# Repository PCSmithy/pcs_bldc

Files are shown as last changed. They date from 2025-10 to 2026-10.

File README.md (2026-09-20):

# pcs_bldc

A learning project for modeling and control of a brushless DC motor.

This is a personal reference project. The primary audience is the author, with
the intent to open-source it as a public example of what I believe quality
embedded software development, state estimation, and motor control should look
like end-to-end.

## Status

- **Hardware:** design finalized, layout complete. The board is frozen pending
  firmware work and will only be revised if firmware exposes a project-blocking
  issue.
- **Firmware:** foundation platform plus first motor drive — a spec'd and
  traced driver stack (clocks, GPIO, ADC, DMA, SPI, I2C, timers, USB CDC,
  op-amps, encoder, LED ring, button, serial) with all board sensing
  bench-verified in engineering units; six-step trapezoidal drive spinning
  the motor through the STSPIN32G4 gate driver, with USB-PD sink
  monitoring and overcurrent / encoder-fault protection; and a
  protobuf-over-USB protocol carrying telemetry, a signal trace engine
  sampling at the 20 kHz PWM rate, a link throughput test, and the log
  stream. FOC and estimation are ahead (see
  [`docs/motor-sprint.md`](docs/motor-sprint.md)).
- **Desktop app:** observability slice working on the bench — connect with
  a firmware-identity gate, DWARF-driven signal picker, live WebGL plots
  with honest min/max decimation, pause/zoom timeline with a comparison
  cursor, value table, and session restore. Spec-driven like the firmware
  ([`specs/desktop-app/`](specs/desktop-app/)), verified by a playwright
  UI suite.
- **Simulation and analysis tooling:** an SIL harness (`sw/sil`) exercises
  the native firmware build (protocol, trace engine, server); the
  high-fidelity motor-model SIL and the formal `notebooks/` analysis
  infrastructure are not yet started (ad-hoc trace analyses live in
  `tools/trace_analysis/`).

The hardware is a USB-PD-powered BLDC controller built around an STM32G431 MCU,
an STSPIN32G4 integrated gate driver, and an AS5048 magnetic rotor encoder. It
will live on the desk as an unloaded test stand; no production load profile is
in scope.

## Setup

Run `./setup.sh` from the repo root. It checks for required system tools
(Java 17+, Python 3.10+; KiCad 10 if you are doing hardware work), prints
install instructions for anything missing, and then installs project-local
artifacts (the OpenFastTrace JAR and the Python virtual environment). It is
idempotent and safe to re-run.

KiCad is required **only** for hardware design work. Contributors working on
firmware, SIL, analysis notebooks, or desktop tooling can ignore a
missing-KiCad warning and proceed.

Supported platforms are Windows and macOS. See
[`docs/setup.md`](docs/setup.md) for the full prerequisite table, what the
script does, verification steps, and troubleshooting.

## Project Goals

The project has four primary goals. Each is treated as a first-class
deliverable with its own specs, tests, and documentation. The goals are not
ordered by priority; they are interdependent and developed together.

### 1. Reference-quality embedded software development

Demonstrate, as a working example, what disciplined embedded software
development looks like end-to-end.

- **Architecture.** FreeRTOS-based, with clean abstraction layers, channelized
  module design for reuse, and no reliance on auto-generated framework code as
  the source of truth for application logic.
- **Spec-driven development with full traceability.** Every line of application
  code links to a software requirement; every requirement links forward to at
  least one test that covers it; every requirement derives from a higher-level
  parent (ultimately a project-goal section in this document). See
  [`docs/spec-system.md`](docs/spec-system.md).
- **Test infrastructure.** Unit tests for module-level logic; high-fidelity
  software-in-the-loop (SIL) tests as the primary verification surface. No
  hardware-in-the-loop (HIL) layer — once the motor is characterized, the SIL
  model is the test bench. Coverage targets are *spec coverage*, not just line
  coverage.
- **CI and quality gates.** Reproducible builds (pinned toolchain in a
  containerized dev environment), static analysis (clang-tidy / cppcheck),
  unit + SIL tests, and spec-traceability checks all enforced on every push.
- **Documentation as deliverable.** Code, specs, and analysis notebooks are
  written for an external reader from day one. The repository is intended to
  be public-ready throughout its life.

### 2. Modeling, simulation, and observability infrastructure

The infrastructure that supports learning and verification is itself a primary
deliverable, not an afterthought.

- **High-fidelity SIL model.** Motor electrical and mechanical model, gate
  driver and bridge model, sensor models (encoder, current shunts, bus
  voltage). Fidelity is set by what the estimators and controllers need to be
  developed and validated against — not by an abstract realism target.
- **System identification feeds the model.** Initial parameters are taken from
  measurements and datasheets to get the motor spinning. Auto-commissioning
  routines and online (augmented-state) parameter identification are scoped as
  later phases.
- **Real-time observability.** Rich USB-streamed telemetry (control loop
  internals, references, estimator states, raw sensor data) at meaningful
  rates, paired with a custom desktop visualizer / control app for live
  inspection, command, and tuning.
- **Offline analysis.** A Jupyter-notebook pipeline for post-hoc analysis with
  derivations, math overlays, and side-by-side comparisons. The notebooks
  carry the academic content of the project and are the primary artifact for
  re-learning estimation and control concepts at depth.
- **Algorithm comparison harness.** Code, SIL scenarios, and analysis pipeline
  structured so that swapping in a new estimator or controller, running the
  standard benchmark trajectories, and producing comparison plots is a small
  and repeatable workflow. The harness is designed to scale across many
  implementations even though the project may only execute on two or three of
  each.

### 3. State estimation

Re-learn and demonstrate optimal-estimation techniques on a real, instrumented
system. Pedagogical clarity and a strong intuition for filter behavior matter
as much as the filter "working."

- **Kalman-family observer** estimating motor position, velocity, acceleration,
  torque, and thermal state from phase currents, phase voltages, and rotor
  encoder position.
- **Validation in SIL before bench.** The SIL/observer pair is used to
  characterize convergence, noise sensitivity, and steady-state error before
  the filter ever sees the real motor.
- **Sensor-degradation experiments.** Systematically drop, delay, or corrupt
  sensor inputs in SIL to characterize filter robustness and to assess the
  feasibility of sensorless operation.
- **Sensorless extension.** Demonstrate sensorless estimation of position and
  velocity using an appropriate observer family (back-EMF, sliding-mode, HFI,
  or similar — selected during design).
- **Future phases.** Auto-commissioning of motor parameters; online
  augmented-state parameter identification.

### 4. Field-oriented motor control

Drive the motor cleanly under a hierarchy of control modes, using estimator
output as the feedback source so that estimation quality directly translates
into control quality.

- **Inner FOC torque loop**, both sensored and sensorless.
- **Outer loops:** constant velocity, constant torque, position control, and
  position trajectory tracking.
- **Repeatable trajectory benchmark.** A canonical position trajectory that
  can be replayed across estimator and controller variants under identical
  conditions, producing standard performance metrics (tracking error, control
  effort, settling time, current ripple, etc.) for side-by-side comparison.
  This benchmark is the primary scenario through which estimator and
  controller variants are evaluated.

## Non-goals

Explicitly out of scope, to keep the project tractable:

- Hardware-in-the-loop infrastructure. SIL is the simulation surface; the
  bench is everything else.
- Production-grade safety certification (DO-178, ISO 26262, or similar).
  Basic protections — overcurrent, overtemp, encoder-loss, gate-driver fault
  handling — are sufficient.
- Loaded operation, multi-motor systems, or specific application profiles
  (servo arm, drone, etc.). The motor is an unloaded desk test stand.
- Hardware revisions, unless firmware work exposes a project-blocking issue
  that cannot be worked around in software.
- Beating commercial motor-control SDKs on raw performance. Comparison against
  a baseline (e.g. ST Motor Control SDK) is interesting if it serves the
  learning goal, but is not a target in itself.

## Repository layout

| Path | Contents |
|---|---|
| `hw/` | KiCad 10 schematic and PCB design |
| `datasheets/`  | Reference PDFs for major ICs |
| `docs/` | Project-level documentation (spec system, setup, backlog) |
| `specs/` | OFT spec tree: `sys~` / `fw~` / `app~` requirements |
| `sw/` | All software: `fw/` firmware, `gui/` desktop app, `sil/` SIL harness, `lib/` shared C + Rust libraries, `proto/` board schema, `cmake/` toolchains |
| `tools/` | Project tooling: OFT wrapper, spec scripts, build scripts |
| `notebooks/` | Jupyter analysis notebooks (planned) |

`CLAUDE.md` contains working notes used by the AI assistant on this project.

## License

- Firmware, tooling, scripts, specs, and docs: **Apache-2.0** ([`LICENSE`](LICENSE)).
- Hardware design in [`hw/`](hw/): **CERN-OHL-W-2.0** ([`hw/LICENSE`](hw/LICENSE)).
- Vendored third-party code keeps its own license.

See [`LICENSES.md`](LICENSES.md) for the full map, including third-party components.

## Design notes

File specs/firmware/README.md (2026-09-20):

# Firmware specs

`fw~` requirements: STM32G4 firmware behavior, written in C/C++ on
FreeRTOS. Each spec needs at least one `impl` tag (in C/C++ source) and at
least one `test` tag (unit and/or SIL).

## Topics

Sub-folders are created when a topic gets its first spec.

- `architecture/` — task structure, ISR design, memory layout, build
  configuration
- `hal/` — hardware abstraction layer (hw-layer peripheral drivers: SPI,
  ADC, GPIO, DMA, timers, USB, op-amps, I2C). Uses per-peripheral sub-topic
  IDs, e.g. `fw~hal_spi_001~1`, `fw~hal_i2c_001~1`, `fw~hal_adc_001~1`,
  `fw~hal_usb_001~1`, `fw~hal_opamp_001~1`
- `io/` — generic, domain-independent io-layer infrastructure drivers (device
  abstractions layered over HAL buses). Per-bus sub-topic IDs, e.g.
  `fw~io_i2c_001~1` (IO_i2c generic per-device I2C driver over HW_I2C),
  `fw~io_bridge_001~1` (IO_bridge 3-phase motor-bridge driver over HW_TIM)
- `pd/` — USB-PD sink status: register decode and runtime for the CYPD3177
  controller, e.g. `fw~pd_001~1` (lib_CYPD3177 decode library)
- `mc/` — motor control, e.g. `fw~mc_001~1` (dev_gateDriver STSPIN32G4
  gate-driver management), `fw~mc_006~1` (app_motorControl gating and
  the PWM-synchronous commutation step), `fw~mc_013~1` (frame transforms
  and space-vector modulation), the six-step and V/f methods; also FOC,
  motion, trajectory tracking
- `est/` — estimation. Per-area sub-topic IDs, e.g. `fw~est_encoder_001~1`
  (AS5048 magnetic encoder driver), `fw~est_velocity_001~1` (encoder-derived
  velocity estimate); also the Kalman observer, sensorless observer, and
  parameter identification
- `obs/` — observability and on-device status indication. Per-area sub-topic
  IDs, e.g. `fw~obs_led_001~1` (SK6805 RGB LED string driver),
  `fw~obs_identity_*` (build identity), `fw~obs_status_001~1` (10 Hz status
  publication), `fw~obs_log_*` (printf log stream)
- `ui/` — on-device user-interface input drivers. Per-area sub-topic IDs, e.g.
  `fw~ui_switch_001~1` (dev_switch debounced button/switch driver)
- `conn/` — device↔app connectivity (the firmware side). Per-area sub-topic
  IDs: `fw~conn_serial_*` (IO_serial byte-stream transport over USB CDC),
  `fw~conn_proto_*` (protobuf schema + IO_COBSFrame framing),
  `fw~conn_server_*` (app_server request dispatch, link throughput
  test), `fw~conn_trace_*` (app_server trace services: PWM-cycle watch
  sampling and batched streaming, memory read/write, trace capability
  report)
- `safety/` — fault state machine, protection thresholds, recovery
  paths

## Tagging conventions in firmware code

```c
// [impl->fw~foc_park_transform~1]
void foc_park_transform(...) { ... }
```

```c
// [test->fw~foc_park_transform~1]
TEST(foc, park_transform_matches_reference) { ... }
```

A single piece of code can carry multiple tags if it implements multiple
specs (rare; usually a sign you should split the code).

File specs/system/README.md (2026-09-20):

# System specs

`sys~` requirements: what the system as a whole must do, including how the
STM32G4 firmware and the Rust desktop app cooperate.

Each `sys~` spec declares which downstream components it requires for
coverage on a per-spec basis:

- `Needs: fw, test` — firmware-only behavior (e.g. closed-loop current
  control runs at 20 kHz on the MCU).
- `Needs: app, test` — desktop-app-only behavior (e.g. the user can change
  the live-plot color scheme).
- `Needs: fw, app, test` — cross-component behavior (e.g. the user can
  configure motor parameters via the GUI and have them persisted in
  firmware NVRAM).

System-level tests are typically SIL scenarios or end-to-end integration
tests that exercise the full stack. SIL is the primary verification surface
for this project.

## Start here

- [[overview|System overview]] — block diagram, two-component architecture,
  external/internal interfaces, operating-mode state machine, persistence,
  plurality. Contains the small set of architectural anchor `sys~` specs
  (standalone device, app as auxiliary, USB CDC transport, mode FSM, NVRAM,
  multi-device).

## Topics

Sub-folders are created when a topic gets its first spec. The topics below
are the anticipated structure; folders that are not yet present have no
specs in them yet.

- `mc/` — sensored & sensorless motor control (anchor `sys~mc_001`), torque,
  velocity, position, trajectory tracking; gate-driver management (anchors
  `sys~mc_002` configuration, `sys~mc_003` fault observability); bridge
  actuation (`sys~mc_004`), the commutation-method architecture
  (`sys~mc_005`), and control-loop timing (`sys~mc_006`)
- `est/` — state estimation, sensorless operation
- `conn/` — device↔app protocol: schema-defined messages
  (`sys~conn_001`), message framing (`sys~conn_002`), request
  acknowledgement (`sys~conn_003`), link throughput test
  (`sys~conn_004`)
- `obs/` — observability: periodic status telemetry (`sys~obs_001`),
  signal selection from firmware debug information (`sys~obs_002`),
  firmware build identity + gate (`sys~obs_003`/`_004`), signal trace
  (`sys~obs_005`), signal write (`sys~obs_006`), text log stream
  (`sys~obs_007`), memory read (`sys~obs_008`), trace capability report
  (`sys~obs_009`)
- `ops/` — system mode state machine (idle / calibrate / run / fault),
  command authority (`sys~ops_002`, [[command-authority]]), mode
  transitions (anchor `sys~ops_001` lives in [[overview]])
- `safety/` — protections (overcurrent, overtemp, encoder-loss,
  gate-driver fault), fault recovery
- `pd/` — USB-PD sink power monitoring (anchor `sys~pd_001`), power-up
  sequencing, brown-out recovery

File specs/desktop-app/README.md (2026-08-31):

# Desktop app specs

`app~` requirements: the Rust + webview desktop app (`sw/gui/`) for
observing, commanding, and configuring the device. Each spec needs at
least one `impl` tag (in Rust source) and at least one `test` tag (unit
and/or integration).

## Topics

Sub-folders are created when a topic gets its first spec.

- `arch/` — process split and state ownership ([[core-ownership]]:
  device and firmware state live in the native core;
  [[session-restore]]: the saved port/ELF/watch-list context)
- `conn/` — device session and protocol client ([[session]]), framing
  + envelope codec ([[wire]])
- `obs/` — the acquisition model: ELF/DWARF signal selection
  ([[signal-picker]]), the build-identity gate ([[access-gate]]), the
  trace client and Samples demultiplexer ([[trace-client]])
- `views/` — presentation surfaces: [[live-plot]] (plot, axes, trace
  appearance, decimation), [[telemetry]], [[log]], [[workspace]],
  [[cursor]] (cursor, pointed trace, comparison anchor + deltas),
  [[table]], [[timeline]], [[watch-panel]], [[render-budget]]
  (rendering performance floor), and [[value-rendering]] (the
  surfaces' shared value formatting)

Convention: `obs/` holds acquisition and access — what bytes mean and
when capabilities are available; `views/` holds presentation surfaces —
what the user sees.

## Tagging conventions in Rust code

```rust
// [impl->app~conn_001~1]
fn open_session(port: &str) -> Result<Session> { ... }
```

```rust
// [test->app~conn_001~1]
#[test]
fn session_reopens_after_port_returns() { ... }
```

A single piece of code can carry multiple tags if it implements multiple
specs (rare; usually a sign you should split the module).

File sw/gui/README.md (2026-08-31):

# pcs_bldc — GUI operator app

A Rust + webview (Tauri 2) desktop app for connecting to the pcs_bldc
board: observability (DWARF signal selection, live trace plotting,
telemetry, logs), command, and diagnosis over the USB serial protocol.
Requirements live in `specs/desktop-app/` (`app~` specs).

Layout:

- `src-tauri/` — the native core (own Cargo workspace + lockfile). All
  device I/O, protocol state, and loaded-ELF state lives here
  (`app~arch_001~1`); shared logic comes from the `sw/lib/rust` crates
  (`pcs_wire`, `pcs_proto`, `dwarf_map`).
- `dist/` — the static webview frontend (no JS toolchain; plain
  HTML/JS served via `frontendDist`, `withGlobalTauri` for `invoke`).

Build/run from `src-tauri/`: `cargo build`, `cargo tauri dev` (or
`cargo run` for the plain window).

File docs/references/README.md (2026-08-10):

# References

Papers backing the project's control design. Large PDFs stay out of the
repo where possible — cite title + DOI here instead.

## Future controls references

- Prabhu, N., Rajaram, T., Ashok, B., "Design of sliding mode model
  predictive dual-loop control through self-learning strategy to mitigate
  the torque ripple in BLDC motor for electric vehicles."
  Scientific Reports 15, 45617 (2025).
  https://doi.org/10.1038/s41598-025-29445-w

## In-repo

- `actuators-14-00400-v2.pdf` — Abouseda, A.I., Doruk, R., Emin, A.,
  Akdeniz, O., "Modeling, Dynamic Characterization, and Performance
  Analysis of a 2.2 kW BLDC Motor Under Fixed Load Torque Levels and
  Variable Speed Inputs: An Experimental Study." Actuators 14, 400 (2025).
  https://doi.org/10.3390/act14080400

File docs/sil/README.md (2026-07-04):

# SIL (Software-in-the-Loop) testing environment

> **Picking this up fresh? Start with [`handover.md`](handover.md)** — current
> status, code map, how to run, and the prioritized next steps.

This directory holds the planning + architecture docs for the pcs_bldc SIL
environment: a Rust framework (**`voyant`**) that runs the **native
cross-compiled C firmware** against simulated plant models, with white-box
inspection of firmware state during execution.

Two run modes share one core engine:

- **Realtime mode** — sim time tracks wall-clock. Hosts a web dashboard
  (signal plotting, injection, live model tweaks) and presents a USB-CDC
  endpoint so the desktop app can't tell it apart from the real board.
- **Fast mode** — faster-than-realtime, fully scripted via Python/pytest
  bindings. Deterministic, parallelizable, for automated regression.

## Build & run

```bash
tools/run_sil.sh            # build native firmware (DLL) + SIL framework, run the sim
tools/run_sil.sh --clean    # wipe the native build dir first
```

Builds the firmware as a shared library (`build/native-fw/src/libpcs_bldc_fw.dll`),
builds the `sw/sil/` Rust workspace, and runs `sil-core`, which loads the
firmware, drives it over the control ABI, and reads its state by symbol.

## Documents

| Doc | Purpose |
|-----|---|
| [`architecture.md`](architecture.md) | The technical architecture: execution model, sim boundary, time/scheduler core, plant models, Rust↔C boundary, the two run modes, and the open decisions. **Read this first.** |
| [`state-route-tables.md`](state-route-tables.md) | The two core framework data structures: the **State Table** (every firmware static + model states; traced entries are change-logged historians) and the **Route Table** (declarative per-tick transport). |
| [`signal-trace.md`](signal-trace.md) | D12 — the State Table as historian: change-logged, timestamped per-signal timeseries that Python tests evaluate against. |
| [`ffi-boundary.md`](ffi-boundary.md) | D2 — Rust↔C boundary: in-process, dynamically-loaded firmware, DWARF memory introspection, tiny control ABI + C→Rust upcalls. |
| [`freertos-tick.md`](freertos-tick.md) | D1 — single-threaded cooperative FreeRTOS **fiber** port + pluggable tick source (realtime vs framework-driven). |
| [`performance.md`](performance.md) | The performance architecture: cost model + levers (fibers, gated discrete work, better integrators, dirty-page historian, zero-alloc) + the seams baked in from the start. |
| [`sim-interrupts.md`](sim-interrupts.md) | D8 — framework-owned interrupt table (periodic + one-shot, config + runtime); dispatched through the port in the firmware fiber context. |
| [`inverter-timestep.md`](inverter-timestep.md) | D6 — inverter fidelity (averaged-duty default, switching-resolved opt-in), the abc model↔firmware contract, and base `dt`. |
| [`time-virtualization.md`](time-virtualization.md) | D9 — firmware time sources backed by the sim clock; every wait is a yield (busy-waits would deadlock). |
| [`determinism.md`](determinism.md) | D7 — tolerance-based float assertions (ε≈1e-6) over a reproducible engine; the discrete threshold-divergence caveat. |
| [`roadmap.md`](roadmap.md) | Phased milestones + status tracking for building it out. |

## Worktree / branch workflow

This work lives on the **`sil`** branch, developed in a separate worktree so
`main` stays free for parallel work:

```
C:/code/pcs_bldc       main   (hardware + firmware)
C:/code/pcs_bldc-sil   sil    (this SIL effort)
```

- **Rebase cadence:** periodically `git fetch && git rebase main` from the
  `sil` worktree to pull in firmware/build changes. The SIL effort requires
  real firmware-side work — running FreeRTOS and the io/dev/app layers on
  the SIM target (today they're gated `BUILD_TARGET_STM32G4`-only), plus a
  sim ABI for the framework to drive. Keep these changes clean and
  upstream-friendly to reduce rebase friction; much of it (ungating layers,
  sim impls of low-level drivers) is genuinely useful on `main` regardless.
- **Merge back:** once the harness is proven, merge `sil` into `main`. The
  firmware-side changes (native FreeRTOS port wiring, ungating the upper
  layers for SIM, sim impls of the bottom-layer drivers, a sim ABI/entry
  point) are the parts that touch shared files; the Rust framework under
  `sw/sil/` is purely additive.

## Confirmed ground rules

1. Framework is **Rust**.
2. Runs the **native** firmware build (`BUILD_TARGET_SIM`), not an ARM
   emulator — for speed, determinism, and parallelism. An ARM-emulation
   backend stays a future option behind a clean execution-backend seam.
3. The sim plugs in at the existing **HAL/channel boundary**
   (`sw/lib/c/shared/hw/<Module>/sim/`). Only the genuinely
   hardware-specific bottom layer is swapped.
4. **FreeRTOS and the io/dev/app layers run on the SIM target too** — the
   real scheduler and the real task code execute in sim, not a re-host of
   the logic. (Today they're gated `BUILD_TARGET_STM32G4`-only; making them
   build + run on SIM is the bulk of the firmware-side work.)
5. White-box inspection is via the **native `.elf`/shared-lib symbol table
   (+ DWARF)** — read/write firmware globals by name during execution. **No
   sim-specific getter/setter functions in the firmware.**
6. The framework's two core data structures are the **State Table** (one
   namespace over every firmware static + all model states) and the **Route
   Table** (per-tick `source → destination` transport). See
   [`state-route-tables.md`](state-route-tables.md).
7. **Single-threaded cooperative fibers, performance-first.** The whole sim runs
   in one OS thread (tasks = fibers); the hot loop is engineered for many×
   realtime on a normal desktop. See [`performance.md`](performance.md).

See [`architecture.md`](architecture.md) for the reasoning and the decisions
still open.

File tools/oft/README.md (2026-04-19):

# OpenFastTrace (project-local install)

This directory holds a project-local install of
[OpenFastTrace](https://github.com/itsallcode/openfasttrace) (OFT), the
spec-traceability tool described in
[`docs/spec-system.md`](../../docs/spec-system.md).

## Requirements

- Java 17 or later on `PATH`. The wrappers will fall back to a
  `C:\Program Files\Microsoft\jdk-*-hotspot` install if `java` is not on
  `PATH` (useful right after a fresh winget install before the shell is
  restarted).

## Setup

The JAR itself is not committed. To download the project-pinned version
and verify its SHA256:

```bash
tools/oft/install.sh
```

Re-running `install.sh` is idempotent.

## Usage

From bash:

```bash
tools/oft/oft.sh trace specs/ src/ test/
tools/oft/oft.sh trace -o html -f trace.html specs/ src/ test/
tools/oft/oft.sh help
```

From cmd.exe:

```
tools\oft\oft.cmd trace specs\ src\ test\
```

## Pinned version

OFT is pinned to **4.2.2**. The version string lives in three files
(`install.sh`, `oft.sh`, `oft.cmd`). To upgrade, edit all three; the SHA256
is fetched from the upstream release alongside the JAR, so there is no
hand-maintained checksum.

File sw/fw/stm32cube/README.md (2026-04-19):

STM32Cube artifacts - driven by HW design, not active development

use converter script to convert cube outputs into /src/ format for project development

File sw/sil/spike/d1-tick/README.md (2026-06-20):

# D1 spike — cooperative fiber FreeRTOS port

Proves the load-bearing assumption of the whole SIL design (see
[`docs/sil/freertos-tick.md`](../../../../docs/sil/freertos-tick.md) §8 and
[`docs/sil/performance.md`](../../../../docs/sil/performance.md) Lever 1):
a **single-threaded cooperative fiber** FreeRTOS port is **deterministic** *and*
**many× faster than realtime**.

## What it is

A native (host) FreeRTOS V10.3.1 build with a hand-written **fiber port**:

- one OS thread; each task is a **Windows fiber**; the driver is the main fiber
- context switches are **fiber swaps** at cooperative points only
- the tick is **framework-driven** — the driver calls `vSilAdvanceTick()`
- quiescence (all tasks blocked → idle) hands control back to the driver via the
  idle hook (`vApplicationIdleHook` → `vPortYieldToScheduler`)

Two tasks exercise the scheduler: **A** (prio 3, 1 ms) and **B** (prio 2, 5 ms).

## Files

| File | Role |
|---|---|
| `port.c` / `portmacro.h` | the cooperative fiber port |
| `FreeRTOSConfig.h` | native config (cooperative, idle-hook handoff, timers off) |
| `spike.c` | driver + two tasks + idle hook; trace and bench modes |
| `build.sh` | build with MinGW gcc |

## Build & run

```bash
bash build.sh
./d1_spike.exe              # trace mode: per-tick task activity to stdout
./d1_spike.exe bench 50000000   # bench mode: ticks/s + x-realtime to stderr
```

## Results (MinGW gcc 15.2, one desktop)

**Determinism — PASS.** 30 serial + 16 parallel runs of trace mode are
**bit-identical**. Trace shows A every tick, B every 5th, A before B when both
are ready (priority order) — correct FreeRTOS scheduling, reproducibly.

**Performance — PASS.** ~**5.0 Mticks/s ≈ 5000× realtime** on one core at a
1 kHz tick — and this is a heavy case (A wakes *every* tick, so every tick does a
full switch in/out). 8 parallel sims hold ~4.3 Mticks/s each (~13% contention
loss) → near-linear scaling.

## What it proves / scope

- Validates the **fiber execution engine** (determinism + throughput) — the
  riskiest assumption — before anything is built on top.
- Raw scheduler-tick cost only; models, routes, historian, and real firmware
  come later and add per-tick cost. At a finer production base `dt` (a few µs),
  ~5 Mticks/s is ~10× realtime for the bare tick before that work.
- Windows fibers directly (Windows-first). The cross-platform context-switch
  primitive (macOS `ucontext` / small asm) is a later roadmap item.
- Throwaway scaffolding: the production port reuses this structure but lives in
  the canonical FreeRTOS portable layout.

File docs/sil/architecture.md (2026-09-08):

# SIL architecture

Status: **draft / planning.** This captures the agreed ground rules and the
decisions still open. It is a living doc — update it as decisions land.

## 1. Goal

A Rust framework that runs the **native cross-compiled pcs_bldc firmware**
against simulated plant models (motor, encoder, sensors, power), with
white-box access to firmware state, in two modes:

- **Realtime** — sim time == wall-clock; web dashboard; presents a USB-CDC
  endpoint the desktop app talks to as if it were the real board.
- **Fast** — faster-than-realtime, deterministic, scripted from Python
  (pytest), parallelizable for regression.

## 2. The big picture

```
            ┌─────────────────────────── Rust SIL framework ──────────────────────────┐
            │                                                                          │
  pytest ──┐  ┌───────────┐   ┌────────────────────────┐   ┌────────────────────────┐
  (fast)   ├──┤ scripting │──▶│        sim core         │◀─▶│  plant models (Rust)   │
           │  │ / py bind │   │  sim clock · run modes  │   │  motor · encoder ·     │
  web UI ──┘  └───────────┘   │  ┌───────────────────┐  │   │  sensors · power       │
 (realtime)  ┌───────────┐    │  │    STATE TABLE    │  │   └───────────┬────────────┘
             │ dashboard │──▶ │  │ every fw static + │  │   model state │ register
             │ (ws+plot) │    │  │   model states    │  │◀──────────────┘
             └───────────┘    │  └───────────────────┘  │
                              │  ┌───────────────────┐  │
                              │  │    ROUTE TABLE    │  │  src→dst transport each tick
                              │  └───────────────────┘  │
                              └────────────┬────────────┘
  control ABI (start / advance_time / dispatch_isr) │  direct memory R/W via DWARF
                                           ▼  (NO sim getters/setters in firmware)
           ┌─────────────── native firmware (BUILD_TARGET_SIM) ──────────────────┐
           │  app · dev · io   (mode FSM, control, estimator, IO, USB)   in SIM   │
           │  ────────── FreeRTOS scheduler (cooperative fiber port · 1 thread) ──│
           │  hw   HW_ADC/SPI/GPIO/systemClock  — only HAL/register code swapped  │
           └─────────────────────────────────────────────────────────────────────┘
```

## 3. Decisions

### 3.1 Confirmed

- **Rust** framework.
- **Native execution**, not ARM emulation. Rationale: fast, deterministic,
  trivially parallel, and it reuses the `sim/` HAL swaps already in the
  tree. ARM emulation (Unicorn/QEMU) is slower and would require modeling
  peripherals at the register level, fighting the existing HAL-level swap.
  Its one advantage — running the bit-exact shipping binary to catch
  32-bit-ARM-vs-host bugs — is not worth the cost now. Kept as a *future
  backend* behind the execution-backend seam (§3.2).
- **Interception at the HAL/channel boundary.** The bottom, register-specific
  layer (`sw/lib/c/shared/hw/<Module>/sim/`) is what's swapped. But the
  framework does **not** call sim getters/setters — it reads/writes the sim
  drivers' (and any other) firmware state directly in memory via the State
  Table (below).
- **FreeRTOS + io/dev/app run in SIM.** We run the *real* scheduler and the
  *real* task code on the native target. Only the bottom, register-specific
  layer is replaced. This is the high-fidelity-where-it's-cheap choice: all
  the control / FSM / estimator / UI logic and its concurrency structure are
  exercised exactly as they ship.
- **Single-threaded cooperative fibers, performance-first.** The whole sim
  (framework + firmware tasks-as-fibers) runs in one OS thread (D1). This is the
  foundation of both determinism and the many×-realtime performance target;
  the hot loop is built around it (gated discrete work, zero-alloc, a pluggable
  historian change-detector). See [`performance.md`](performance.md).
- **State Table + Route Table are the framework's core data structures**
  (see [`state-route-tables.md`](state-route-tables.md)). The **State Table**
  is one namespace over *every* firmware static (auto-derived from DWARF) plus
  all model states; the **Route Table** declaratively transports
  source→destination each tick. This replaces any sim-specific data API in the
  firmware entirely.
- **White-box via symbols, no firmware instrumentation.** Read/write any
  firmware global by name through the native shared-lib symbol table + DWARF
  (types/addresses), dereferenced in-process. No hand-written accessor per
  signal; the firmware doesn't know it's being simulated.

### 3.2 The public member seam and the internal execution backend

The framework's one **public** seam onto everything it executes is the
**`Member`** trait (see "Member model" below): the engine drives firmware
instances, plant models, and future native apps uniformly through it. Firmware is
one *kind* of member — a **`FirmwareMember`** wrapping the concrete **`Firmware`**
handle (native shared lib + DWARF white-box; white-box `read_cvar`/`write_cvar`
and lifecycle `start`/`shutdown` are inherent methods on that handle).

Behind `FirmwareMember` sits an **internal, crate-private** `Backend` trait — the
narrow execution seam the member drives *around each tick*:

```rust
pub(crate) trait Backend {
    fn advance_time(&self, elapsed_us: u64);   // move the firmware's hardware timebase
    fn dispatch_isr(&self, handler: usize) -> bool; // run one handler in the ISR bracket
    fn read_cvar(&self, path: &str) -> Value;  // white-box read
    fn write_cvar(&self, path: &str, v: &Value); // white-box write / injection
    // + the port registration seam (defaults to no-ops)
}
```

It is **not** a public architectural seam. Its value is the in-crate test double
(mock backends prove `FirmwareMember`/engine semantics without a firmware DLL),
and it keeps the door open for a second execution mechanism to slot in behind
`FirmwareMember` without disturbing the engine, models, or modes. Lifecycle
(`start`/`shutdown`) and DLL loading are deliberately *off* the trait — they are
called on the concrete `Firmware` handle the driver holds.

- `Firmware` (native shared lib) — the first and primary backend (§4).
- `ArmEmu` — a possible later impl (Unicorn/QEMU) for a high-fidelity
  subset, same internal trait.

### 3.3 Open decisions (to resolve)

| # | Decision | Options | Leaning |
|---|---|---|---|
| D1 | **FreeRTOS execution / time source** | — | **RESOLVED:** single-threaded **cooperative fiber port** (tasks = fibers, framework = main context, one OS thread) + pluggable tick source (realtime-paced vs framework-driven). Chosen for determinism *and* performance over OS-thread host ports. See [`freertos-tick.md`](freertos-tick.md) + [`performance.md`](performance.md). |
| D2 | **Rust↔C boundary** | — | **RESOLVED:** in-process, one fw instance/process, firmware as a dynamically-loaded shared lib; tiny control ABI only; all data via direct DWARF-located memory R/W (no sim getters/setters), surfaced as the State Table + Route Table. See [`ffi-boundary.md`](ffi-boundary.md) + [`state-route-tables.md`](state-route-tables.md). |
| D3 | **Python binding** | `pyo3` native extension vs C-ABI + `cffi`/`ctypes` | TBD (pyo3 likely) |
| D4 | **Dashboard stack** | Rust web framework (axum/...) + frontend plotting lib | TBD |
| D5 | **Sim USB-CDC transport** | virtual COM port (Win + macOS) vs TCP socket the app opts into | TBD; ties to the deferred CDC framing decision in `specs/system/overview.md` |
| D6 | **Inverter fidelity / base dt** | — | **RESOLVED (contract):** averaged-duty default, switching-resolved swappable; abc contract (normalized leg duty in, currents+angle out) routed via sim HW-driver state; base `dt` set by model stability (finer than PWM), control ISR fires on a multiple, model advances one `dt`/tick. Two values finalize with the firmware. See [`inverter-timestep.md`](inverter-timestep.md). |
| D7 | **Determinism & float tolerance** | — | **RESOLVED:** tolerance-based float assertions everywhere (default ε≈1e-6, per-signal override), no bit-exact contract; engine stays reproducible (deterministic scheduling + one seeded PRNG) so ε-tests don't flake; mind discrete threshold-divergence; behavioral-within-tolerance vs hardware. See [`determinism.md`](determinism.md). |
| D8 | **Simulated interrupt model** | — | **RESOLVED:** framework-owned interrupt table (periodic + one-shot; registered at config by name and at runtime by the sim HW layer via a C→Rust upcall); dispatched through the port in the firmware fiber context; fixed base-`dt` grid; priority-ordered, no nesting. See [`sim-interrupts.md`](sim-interrupts.md). |
| D9 | **Firmware time virtualization** | — | **RESOLVED:** sim time advances only at yields — every wait is a yield, every time read reflects the sim clock. Reads (`HAL_GetTick`/DWT/timer CNT) are sim-clock-derived; delays become cooperative sim-time advances; portable code uses FreeRTOS delays or a `HW_time` shim. See [`time-virtualization.md`](time-virtualization.md). |
| D10 | **Scenario / config representation** | how a test declares routes + model params + injection (config file? Python API? both) | TBD; the day-to-day test-authoring surface |
| D11 | **State Table binding stability** | symbol-path keys across fw rebuilds — fail-loud at load vs lazy | TBD; small convention |
| D12 | **Signal trace format** | — | **RESOLVED:** the State Table *is* the historian — each traced entry is a change-logged, timestamped time series (ZOH). Whole namespace traced by default (stacks/large arrays excluded); discretes exact, floats on an ε-deadband (default 1e-3, per-signal). Fast mode unbounded; realtime rolls to disk; MDF4 export. See [`signal-trace.md`](signal-trace.md). |

## 4. Execution model (the crux)

Today the native `main()` runs the `HW_*_init` calls and returns — FreeRTOS,
the `task_1ms`/`ledTask` loops, and all io/dev code are gated
`BUILD_TARGET_STM32G4`-only. The decided direction is to **run FreeRTOS and
the upper layers in SIM**, which means:

**Firmware-side work (on `main`-mergeable):**

1. **Ungate the upper layers for SIM.** Move io / dev / app and the FreeRTOS
   bring-up out of the `#if (BUILD_TARGET == BUILD_TARGET_STM32G4)` blocks in
   `main.c`, and make their `CMakeLists` build for both targets.
2. **Sim impls of the bottom-layer drivers** the upper layers sit on. HW
   already has `sim/` for ADC/SPI/GPIO/systemClock. The gaps are the things
   currently STM32G4-only: USB (tinyusb) → a sim CDC transport, and anything
   else that pokes hardware directly. IO modules (AS5048, SK6805) ride on
   `HW_SPI`, so they should build for SIM once SPI's sim behavior carries the
   encoder/LED model data.
3. **A single-threaded cooperative FreeRTOS fiber port + pluggable tick source**
   (decision D1, resolved — see [`freertos-tick.md`](freertos-tick.md) +
   [`performance.md`](performance.md)). Tasks are fibers, the framework is the
   main context, all in one OS thread; the tick comes from a swappable source —
   wall-clock-paced (realtime) or framework-driven (deterministic). Chosen over
   the OS-thread host ports for determinism *and* performance (fiber swaps
   ~30–100 ns vs ~1–5 µs OS-thread switches, no cross-thread signaling). We
   author the fiber port rather than vendoring a host port.
4. **A sim ABI / native entry point** so the `FwBackend` can `init()` and
   `advance()` the firmware and the framework owns the outer loop (rather
   than `vTaskStartScheduler()` never returning).

**What this buys:** the real task priorities, blocking, scheduling order, and
sim-time timing of the shipping firmware are all under test — not a
reimplementation. (Preemption is *cooperative* — faithful in sim-time because
firmware bursts are instantaneous, with one fidelity trade noted in
[`freertos-tick.md`](freertos-tick.md) §5.)

## Member model

Everything the sim executes is a **`Member`** — the framework's single, uniform
seam. The [`Engine`](#5-sim-core-rust) holds shared members (`Rc<RefCell<dyn
Member>>`) and drives each one *only* through this trait, in registration order
(deterministic). `add_member` takes the member **by value** and returns a typed
handle (`Rc<RefCell<M>>`): ignorable for a plain model, or — when `M` also impls
`DuplexPeer` — linked straight to a bus so one struct fills both roles.

```rust
pub trait Member {
    fn name(&self) -> &str;                                    // instance name = <source> of its signals
    fn advance(&mut self, dt_us: u64, ctx: &mut MemberCtx);    // one deterministic step
    fn set_enabled(&mut self, on: bool, st: &mut StateTable);
}
```

`MemberCtx` is the initiator seam the engine hands each `advance`: `ctx.st` is the
State Table (register / record / read), and `ctx.duplex_transfer(handle, tx)` runs a
synchronous serial exchange against a linked peer (the model-side twin of the
firmware's C SPI upcall — both drive the engine's one shared `DuplexRouter`).

Members do **not** declare their signals (`signals()`) and are **not** pulled
(`read()`). Instead a member treats the State Table as its live workspace: it
**registers** its signals as a runtime act directly on the table (inside
`set_enabled(true)` / `advance`), **pushes** its outputs via `StateTable::record`,
and reads its routed inputs via `StateTable::current_value`. Registration is open
(see [`state-route-tables.md`](state-route-tables.md) §1): any member may register
any `sig_type`, and nothing infers a member's kind from what it registers. All
cross-member coupling flows through **routes**, never one member reaching into
another's signals (a discipline convention, not enforced — members are first-party
trusted code; a narrowed per-member table view is the escalation if scripted
members ever change the trust model).

**The firmware is one *kind* of member.** A **`FirmwareMember`** wraps a concrete
**`Firmware`** handle (DLL load, lifecycle, DWARF white-box) and drives it through
the internal, crate-private `Backend` seam (§3.2) — which demotes from "the
firmware seam" to internal plumbing behind the member. It is constructed with an
explicit instance **`name`** (not derived from the DLL — two boards may run the
same image as distinct members); its `advance` moves the firmware's timebase,
**flushes** the *fresh* (route-/test-written) `cvar`s in its namespace into
firmware memory, dispatches every interrupt due at this sim time, then
**sweeps** its whole cvar leaf list back out into the table
(`record_mirror`). The cvar mirror is **automatic** — the member enumerates the
firmware's traceable namespace from DWARF at enable (minus a built-in
array-size/pointer exclusion policy; skip/register calls tune it) and mirrors it
with **no per-signal declarations** (the D12 end-state). The flush is sparse (a
State Table **dirty set** tracks command writes; writes are one-shot,
last-writer-wins). It is the **only** thing that touches firmware memory — routes never do
(they are table-mediated; see
[`state-route-tables.md`](state-route-tables.md) §2). Lifecycle (`start`/`shutdown`)
stays an explicit call on the concrete `Firmware` handle the driver holds.
Multi-firmware is simply multiple `FirmwareMember`s, each syncing through its own
backend.

**Firmware ports.** A firmware member's sim HW drivers can register signals of
their own at runtime — **ports** — through a hook vtable the framework installs
over the control ABI (`sil_fw_setHooks`, before `sil_fw_start`; the null-safe
`SIL_ports` C helper wraps it, so hookless standalone/unit-test runs are
unchanged). Ports carry **native-format** values (volts stay volts; the driver
owns conversion to its C representation), and their I/O is **cache-mediated**
exactly like the cvar mirror — the member fills every port's input cache
from the table before the step's handlers dispatch and drains the port-write
buffer back into the table after them, so C never touches the State Table
mid-step. The C side
names only `{sig_type, local, unit}`; the member prefixes its instance name. The
sim `HW_ADC` (one input port per enabled input, volts→counts in the driver,
synthetic-ramp fallback when undriven) is the first user. See
[`state-route-tables.md`](state-route-tables.md) §1 "Ports".

**Multi-instance vision.** Firmware instances, plant/peer models, and future native
apps are all **peers** — members side by side in one engine. The `<source>` segment
of a signal's id names its producing member, so *N* firmware instances (the
multi-device stretch goal) and their models coexist in one flat State Table.
`RampModel` is voyant's reference model member; real plant models (motor, encoder,
sensors) are instantiation-side members.

**Enable semantics.** Members start enabled when added. The engine **gates** a
disabled member out — its `advance` is skipped while sim time keeps flowing, and
its signals hold their last recorded value (a firmware member disabled = **held in
reset**: memory frozen, sim time flowing). `set_enabled` is where a member
(re-)registers its signals (idempotent) and runs its member-kind-specific *re-enable
depth*. A `FirmwareMember` with a **reload recipe** (`set_reload_path`) reboots on
re-enable: it shuts the old image down, drops its `Rc` (sole ownership), reloads the
same path from reset, and rebuilds every image-bound cache — State-Table entries
re-register idempotently, so signal history is preserved across the reload. Without a
recipe, re-enable resumes advancing. A model member's own reinit (integration state)
is the same seam when a model wants it.

The per-tick order the engine runs — advance sim time → validate wiring if dirty →
propagate delayed routes from a pre-tick snapshot → for each enabled member:
resolve the zero-latency route DAG (topo order, fresh reads) then advance — and the
**settled per-route latency** model (0 forward / 1 delayed ZOH cut) are documented
in [`state-route-tables.md`](state-route-tables.md) §3. Member registration order is
a design surface for forward flow; the step-time validator flags a route that needs
to be delayed or reordered.

## 5. Sim core (Rust)

One **sim clock** drives a discrete time-step engine at a fixed base `dt`
(D6; set by model numerical stability, typically finer than the PWM rate, with
ISRs firing on integer multiples). State flows through the State
Table; the Route Table moves it (see
[`state-route-tables.md`](state-route-tables.md) §3 for the settled per-route
latency model). Each step:

1. Advance sim time; **validate the wiring if dirty** (acyclic zero-latency graph,
   forward flow along member order, single-driver) — a bad verdict is raised at
   this step and cached until fixed.
2. **Propagate delayed (latency-1) routes** from a snapshot taken before any member
   advances — each delayed destination gets its source's end-of-previous-tick value
   (the ZOH cut).
3. **For each enabled member, in registration order:** re-resolve the enabled
   **zero-latency** routes in topological order with fresh reads (forward dataflow,
   zero added latency), then advance the member. This is **table-only**: routes move
   values between entries and never touch a backend; the firmware member flushes the
   fresh (route-written) `cvar` destinations into firmware memory and sweeps its
   whole cvar mirror back out inside its own advance (each `sil_fw_dispatch_isr`
   runs to quiescence — race-free, the firmware is quiescent here, D1).
4. Append changed signals to the State Table historian (change-logged,
   per-signal timeseries — D12); run test asserts/injection (ad-hoc State
   Table reads/writes). The `Engine` holds **no backend handle** — it touches
   only members, routes, and the table.

The State Table also owns a **unified log system**: a bounded, drop-oldest ring of
`LogEntry { time_us, level, source, message }` that members and the driver append to
via `StateTable::log(level, source, msg)`. The table stamps each entry with its
*current sim time* (members cannot fake a timestamp, and logging never feeds back
into behaviour — determinism is untouched); the driver drains it with `take_logs`.
The swallowed-`record`-error sites now log a `Warning` instead of dropping the error.

The two run modes are thin wrappers over this loop:

- **Realtime:** pace step 3 to wall-clock (sleep/spin so sim-time tracks real
  time), serve the dashboard over WebSocket, and bridge the firmware's CDC
  endpoint to a host virtual COM port / socket (D5) for the desktop app.
- **Fast:** no pacing, no UI. Drive from the scripting API; expose Python
  bindings (D3) for pytest. Deterministic (D1, D7) → reproducible and
  parallelizable across processes (one firmware instance per process).

## 6. Plant models (Rust)

Behind traits so they're swappable and configurable (live in realtime,
per-test in fast mode):

- **Motor** — electrical (3-phase / dq) + mechanical (inertia, friction,
  load torque). Input: inverter command from firmware (PWM duty / phase
  voltages). Output: phase currents, rotor angle + speed.
- **Encoder (AS5048)** — rotor angle → SPI response bytes.
- **Sensors** — phase-current shunts, bus voltage, temperature → ADC counts.
- **Power / USB-PD** — bus/supply behavior.

The model↔firmware contract (what's sampled, at what rate, averaged vs
switching-resolved) is set by D6.

## 7. Code layout — generic framework + instantiation

The framework is a **generic, firmware-agnostic crate** (`voyant`) that could
stand alone / be open-sourced; this board is just an **instantiation** that
implements voyant's trait seams. Nothing board-specific lives in `voyant`.

```
sw/sil/                 Rust cargo workspace
  voyant/                THE FRAMEWORK (generic, no pcs_bldc): the native
                         firmware backend (control ABI + DWARF white-box), and
                         the State Table, Route Table, sim clock, historian, run
                         modes, plus the trait seams a project implements:
                           Member    — any executable participant (the engine
                                       drives everything through this); a model
                                       member, or a FirmwareMember wrapping the
                                       concrete Firmware handle. (An internal,
                                       crate-private Backend trait is the
                                       test-double seam behind FirmwareMember —
                                       not something a project implements.)
                           Transport — a comms bus (tx → rx, completion timing)
                           Scenario  — the project's wiring (members/routes/trace)
  pcs_bldc_sil/          THE INSTANTIATION: impls voyant's traits for this board
                         (motor/encoder/sensor models, firmware config, routes).
                         A lib (src/) exposes `Sil` — the simulation itself, derefing
                         to its `Engine`. `Sil::new()` is a zero-firmware world;
                         `sim.load_firmware(name)` boots one instance per call (image
                         copied per load), and drop unloads + deletes the copies. Each
                         scenario is an independent `#[test]` in tests/*.rs; the perf
                         bin (main.rs) prints the per-tick performance report.
sw/fw/src/                firmware control ABI + native entry / fiber-port wiring
sw/lib/c/shared/hw/*/sim/ bottom-layer sim drivers (no sim getters/setters)
docs/sil/                 these docs
```

(Dashboard + Python bindings become further crates/members as they land. The
framework is developed in-repo now and is extractable to its own repo later —
the `voyant` ↔ `pcs_bldc_sil` boundary already enforces the no-board-code rule.)

Formal OFT specs for the SIL infra are deferred until the design firms up;
a new `sil` topic in `docs/spec-system.md`'s canonical table would be the
home for `fw~sil_*` requirements when we get there.

## 8. Risks / things to prove early

- **D1 spike** — a deterministic, framework-driven FreeRTOS tick on the host
  is the single highest-risk piece. Design is resolved
  ([`freertos-tick.md`](freertos-tick.md)); prove it with the two-task
  spike (§6 there) before building models on top.
- **Float determinism across Win/macOS** (D7) — decide early whether
  regression baselines are byte-exact or tolerance-based; it shapes how
  models and reductions are written.
- **USB-CDC sim transport** (D5) — coupled to the still-undecided CDC framing
  protocol; the desktop-app-as-indistinguishable goal depends on it.
- **Rebase friction** — the firmware-side changes touch `main.c` and module
  `CMakeLists`; keep them small, well-factored, and individually
  `main`-mergeable.

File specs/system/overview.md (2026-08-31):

---
status: draft
tags: [system, architecture, overview]
---

# System overview

This document describes the `pcs_bldc` system at the architectural level: what
it is, what its major pieces are, how they cooperate, and the small set of
foundational `sys~` specifications that anchor those choices. Topic-specific
behavioral specs (motor control, estimation, observability, etc.) live in
sibling files under `specs/system/<topic>/`.

## Purpose

`pcs_bldc` is a USB-PD-powered, single-axis BLDC motor controller used as a
benchtop development platform for learning state estimation and motor
control. It is a **standalone, fully-operational device** with on-device
controls, augmented (but not gated) by an optional desktop application that
provides observability, configuration, diagnostics, and scripted operation.

## Block diagram

```text
  ┌─────────────────────┐
  │   Desktop app       │      USB CDC (virtual COM)
  │   (Rust, optional)  │─────schema-defined protocol─────┐
  │                     │                                 │
  │   - Live plotting   │                                 │
  │   - Configuration   │                                 │
  │   - Diagnostics     │                                 ▼
  │   - Scripted runs   │                  ┌──────────────────────────┐
  │   - Multi-device    │                  │   pcs_bldc device        │
  └─────────────────────┘                  │                          │
                                           │   STM32G431 firmware     │
   On-device UI ─────────────────────────► │   (C/C++ on FreeRTOS)    │
   - Control knob + encoder                │                          │
   - Mode-select button                    │   - FOC control          │
   - RGB status LEDs                       │   - Kalman estimator     │
                                           │   - Mode FSM             │
   AS5048 magnetic encoder ──────────────► │   - On-device UI logic   │
   (rotor position)                        │   - NVRAM (flash-based)  │
                                           │   - Telemetry stream     │
                                           │                          │
                                           │   STSPIN32G4 gate driver │
                                           │   + 3-phase bridge       │
                                           └────────────┬─────────────┘
                                                        │ 3-phase
                                                        ▼
                                                ┌────────────────┐
                                                │   BLDC motor   │
                                                │   (unloaded)   │
                                                └────────────────┘

  Power input: USB-PD (CYPD3177 sink controller) → 5V buck (LMR50410)
```

## The two software components

| Component | Language | Hosted on | Required? |
|---|---|---|---|
| Firmware | C / C++ | STM32G431 (FreeRTOS)  | Always |
| Desktop app | Rust | Windows / macOS host  | Optional  |

The firmware is **primary**: it owns the device's behavior, the operating-mode
state machine, on-device UI, control loops, estimator, and persistence. The
desktop app is **auxiliary**: it adds capabilities that benefit from a
keyboard, screen, and disk — observability plots, parameter configuration,
diagnostic queries, scripted/preset operation, and (stretch goal) coordinated
multi-device control. The device must be fully usable with the app
disconnected.

## External interfaces (system boundary)

- **USB 1** — power input via USB-PD over USB-C cable. Negotiated
  by the CYPD3177; stepped to 5V by the LMR50410 buck.
- **USB 2** - data over USB-C cable between the device and PC for data exchange between the motor driver device and the desktop app
- **Three-phase motor output** — driven by the STSPIN32G4-integrated bridge,
  current-sensed via per-phase shunts.
- **AS5048 magnetic rotor encoder** — over SPI, providing 14-bit absolute
  rotor position for sensored operation.
- **On-device user controls** — a control knob with encoder, a
  push-button for mode selection, and several RGB status LEDs. These provide
  the standalone-mode user experience.

## Internal interface — firmware ↔ desktop app

- Transport: **USB CDC** (virtual COM port). No special drivers on either
  Windows or macOS.
- Direction: **bidirectional**. Commands flow down (mode changes, setpoints,
  parameter writes); telemetry flows up (control loop internals, references,
  estimator state, raw sensor data).
- Protocol: schema-defined protocol-buffer messages in CRC-validated
  frames — `sys~conn_001~1` (schema), `sys~conn_002~1` (framing),
  `sys~conn_003~1` (request acknowledgement), under `specs/system/conn/`.
- Disconnection: the firmware must continue executing whatever mode it was
  last commanded to when the host disconnects mid-session; the app must
  handle disconnect gracefully and reconnect when the device returns.

## Operating modes (high-level state machine)

```text
                     ┌─────────────┐
                     │   Idle      │  Bridge disabled, accepting commands
                     │             │  Default state at boot
                     └──┬────┬─────┘
                        │    │
              ┌─────────┘    └─────────┐
              ▼                        ▼
       ┌────────────┐            ┌────────────┐
       │ Calibrate  │            │   Run      │
       │            │            │            │  Sub-modes:
       │ Encoder    │            │ Closed-loop│   - Torque
       │ offset,    │            │ control    │   - Velocity
       │ param ID   │            │ active     │   - Position
       └─────┬──────┘            └──────┬─────┘   - Trajectory
             │                          │
             └────────────┬─────────────┘
                          │
                          ▼
                   ┌─────────────┐
                   │   Fault     │  Protection tripped, bridge disabled
                   │             │  Requires explicit clear (button or app)
                   └─────────────┘
```

Mode transitions can be triggered by either source:

- The **on-device button** (and knob, for setpoint changes within a mode).
- The **desktop app** (when connected).

Both inputs flow into the same mode-management logic; the firmware does not
distinguish source. Faults always disable the bridge and require an explicit
clear.

## Persistence

Settings that must survive power cycles are persisted in the STM32G431's
internal flash via an NVRAM library (no external EEPROM is fitted). The
implementation choice is between **littlefs** (general-purpose embedded
filesystem) and an **emulated-EEPROM middleware** (ST's X-CUBE-EEPROM or
similar). Decision is deferred and will live in a `fw~` spec under
`specs/firmware/persistence/`.

Persistent items (initial set):

- Motor parameters: R, L, Kt, J, B.
- Encoder calibration: zero offset, direction, electrical-pole-pair count.
- User preferences: any on-device UI defaults, last-active mode/setpoint.

The desktop app is *not* the source of truth for any of these — it can read
and write them, but the firmware owns the canonical values.

## Plurality

- A single physical device serves a single user at any moment via its
  on-device controls.
- The desktop app shall be capable of discovering and connecting to multiple
  devices simultaneously, presenting each with its own UI panel.
- **Stretch:** coordinated position-trajectory control across multiple
  devices (e.g. a master trajectory replayed in lockstep across N devices
  for comparative experiments).

## Constraints and non-goals

(Repeated here for context; see `README.md` for the canonical project-goal
list.)

- The motor is unloaded; no production load profile is in scope.
- HIL is not a project goal; SIL is the simulation surface.
- Basic safety only — overcurrent, overtemp, encoder-loss, gate-driver
  fault. No certification target.
- Hardware is frozen unless firmware work uncovers a project-blocking issue.

## Roadmap milestones

For navigation only — milestones do not have spec IDs.

- **MVP 1.** Motor spins under commanded constant velocity, with on-device
  setpoint via the knob; live measured-velocity plot streamed to the
  desktop app over USB CDC. Single hard-coded set of motor parameters.
- **MVP 2.** Position state estimation (Kalman family) and closed-loop
  position control, with the same standalone-plus-app pattern.
- **Beyond.** Auto-commissioning of motor parameters; sensorless estimation
  experiments; sensor-degradation studies; stretch coordinated multi-device
  control.

## Anchor specifications

These are the small set of cross-cutting `sys~` requirements that anchor the
architecture. Topic-specific behavioral specs (e.g. for FOC, estimator,
trajectory tracking, telemetry framing) live under `specs/system/<topic>/`
and trace to whichever of these anchors are relevant.

### Device standalone operation
`sys~arch_001~1`

The device shall be fully operational with no host computer or desktop
application connected. All primary operations — mode selection (Idle,
Calibrate, Run-with-sub-mode), setpoint adjustment, fault clearing, and
status reporting — shall be available through the on-device controls
(button, knob, RGB LEDs).

Acceptance:

- With USB connected for power only (no host enumerating the data
  interface), the device boots into Idle, allows the user to enter
  Calibrate and Run modes via the button, allows in-mode setpoint
  adjustment via the knob, and reports current mode and fault state via
  the RGB LEDs.
- A bench scenario exercising every supported mode end-to-end completes
  successfully without any host-side software.

Covers:

- (project goal: README.md, "Reference-quality embedded software
  development" — the firmware owns the device experience and is not
  dependent on auto-generated framework code or external orchestration.)

Needs: fw, test

### Desktop app as auxiliary capability
`sys~arch_002~1`

The desktop application shall provide observability, control,
configuration, diagnostics, and scripted-operation capabilities that
augment but do not replace the device's standalone functionality. The
app is optional; its absence shall not impair any standalone device
behavior.

Acceptance:

- The app exposes UIs for: live telemetry plotting, device control (mode
  selection, setpoint adjustment, and fault clearing per `sys~ops_001~1`),
  motor-parameter and user-preference configuration, diagnostic queries
  (firmware version, fault history, current mode), and scripted operation
  (preset trajectories).
- Disconnecting the app at any time during device operation does not
  affect the firmware's ongoing mode or control behavior.
- Each detailed app capability is covered by its own `app~` spec under
  `specs/desktop-app/`.

Covers:

- (project goal: README.md, "Modeling, simulation, and observability
  infrastructure" — the desktop visualizer / control app.)

Needs: app, test

### USB CDC transport
`sys~arch_003~1`

The firmware and desktop app shall communicate over a USB CDC (virtual
serial port) interface carrying the protocol defined in `sys~conn_001~1`.

Acceptance:

- The device enumerates on Windows and macOS using the OS in-box CDC
  class driver.
- A round-trip request/response exchange succeeds over the open port.

Covers:

- (project goal: README.md, "Modeling, simulation, and observability
  infrastructure" — telemetry streaming + control surface.)

Needs: fw, app, test

### Operating mode state machine
`sys~ops_001~1`

The firmware shall implement a mode state machine with the top-level
states **Idle**, **Calibrate**, **Run**, and **Fault**. Run shall have
sub-modes for **Torque**, **Velocity**, **Position**, and **Trajectory**
control. Mode transitions shall be triggerable from either the on-device
button or a desktop-app command and shall be processed identically
regardless of source. Fault shall always disable the bridge and shall
require an explicit clear command (button long-press or app command).

Acceptance:

- Every documented transition is exercisable in SIL and on the bench.
- An Idle → Run transition with no Calibrate run since boot is rejected
  if calibration data is absent (encoder offset unset).
- A fault entered from any Run sub-mode disables the bridge within the
  fault response time budget (TBD in safety specs).
- The mode-management code path is identical whether the trigger source
  is the button or the app.

Covers:

- (project goal: README.md, "Reference-quality embedded software
  development" — clean abstraction and channelized design.)

Needs: fw, test

### Persistence in flash NVRAM
`sys~persist_001~1`

The firmware shall persist motor parameters, encoder calibration data,
and user preferences in the STM32G431's internal flash via a
flash-based NVRAM mechanism (specific implementation chosen in a `fw~`
spec). Persisted values shall survive power cycles and shall be the
firmware's source of truth — the desktop app may read and write these
values but does not own them.

Acceptance:

- A round-trip write (via app or on-device UI) followed by power cycle
  followed by read returns the written value.
- A power loss during write does not corrupt previously-persisted
  values.
- On a fresh device with no prior writes, reads return defined defaults.

Covers:

- (project goal: README.md, "Reference-quality embedded software
  development" — persistent device state, owned by firmware.)

Needs: fw, test

### Multi-device support in the desktop app (stretch)
`sys~arch_004~1`

The desktop application shall be capable of discovering, connecting to,
and operating multiple `pcs_bldc` devices simultaneously. Each device
shall be presented as its own UI panel; commands and telemetry shall be
fully isolated between devices.

Acceptance:

- With N ≥ 2 devices physically connected, the app discovers and lists
  all of them.
- Issuing a command to one device does not affect the others.
- Telemetry streams from all connected devices are decoded and rendered
  concurrently without dropped frames at the working data rate.

Covers:

- (project goal: README.md, "Field-oriented motor control" — repeatable
  trajectory benchmark; multi-device coordination is a stretch goal that
  enables comparative experiments across identical hardware.)

Needs: app, test

### Hardware abstraction layer for representative simulation
`sys~arch_005~1`

The firmware shall isolate all MCU-peripheral access behind a hardware-
abstraction (HW) layer whose modules present an identical, target-independent
API across the embedded (STM32G4) and simulation (SIM) build targets, so that
IO-, device-, and application-layer code can be exercised unchanged in a
high-fidelity SIL environment. Each HW module shall be self-contained and
reusable across projects without modification, with only its channel/bus
configuration and target-specific implementation supplied per project.

Acceptance:

- Every HW-layer module compiles and links for both STM32G4 and SIM behind
  a single consumer-facing header API.
- IO/dev/app code built against the HW API requires no source changes to
  move between targets; only the channel/bus configuration and the
  target-specific HW implementation differ.
- A HW module can be dropped into a separate project and built for both
  targets with only its channel/bus configuration supplied by the new
  project.

Covers:

- (project goal: README.md, "Reference-quality embedded software
  development" + "Modeling, simulation, and observability infrastructure" —
  SIL is the primary validation surface, which requires well-contained,
  reusable hardware abstractions with target-swappable implementations.)

Needs: fw, test

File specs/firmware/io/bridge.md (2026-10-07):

---
status: draft
tags: [firmware, io, bridge, driver]
---

# Bridge io-layer driver

The `IO_bridge` driver is the generic io-layer three-phase motor-bridge
abstraction over `HW_TIM`. It presents normalized per-phase duty commands, a
per-phase output enable, and a whole-bridge output enable, addressed by logical
bridge and phase; each phase maps to a configured HW_TIM logical channel, and a
bridge's three phases share one HW_TIM peripheral whose master output enable
gates the bridge.

See also: [[overview]] (`sys~arch_005~1`), [[tim]] (HW_TIM supplies the
complementary PWM), [[bridge-actuation]] (`sys~mc_004~1`),
[[motor-control-application]] (`fw~mc_015~1` runs the commutation step from
the per-cycle callback).

## Driver configuration and lifecycle

### Initialization and configuration validation
`fw~io_bridge_001~1`

The driver shall validate the supplied configuration and initialize every
configured bridge, returning false on any of:

| Element | Rejected when |
|---|---|
| Config  | The config pointer or its channel array is NULL, or the bridge count exceeds the available bridges. |
| Phase | A phase's HW_TIM channel is out of range. |
| Bridge  | The three phases do not resolve to one shared HW_TIM peripheral. |
| Bridges | An ADC channel carries injected phase senses of more than one bridge. |
| Phase | A phase's complement is itself, or names a phase whose own complement is not it (the derived phase carries none). |

Acceptance:
- A valid configuration initializes every bridge, enables each phase's
  output-compare unit, leaves the master output enable clear, and returns true.
- Each rejection condition returns false.

Covers:
- `sys~arch_005~1`

Needs: impl, test

## Bridge actuation

### Per-phase duty command
`fw~io_bridge_002~1`

The driver shall apply a per-phase duty command in [0, 1] to the phase's
output-compare unit as the fraction of the PWM period during which the phase's
primary output is active, returning false for a command outside [0, 1], an
out-of-range bridge or phase, or an uninitialized driver.

Acceptance:
- Duty commands of 0, 0.5, and 1 produce compare values of zero, half, and the
  full timer period on the phase's output-compare unit.
- Each rejected command returns false and leaves every compare value unchanged.

Covers:
- `sys~mc_004~1`

Needs: impl, test

### Bridge output enable
`fw~io_bridge_003~1`

The driver shall set and report the whole-bridge output-enable state through the
phases' shared master output enable (`fw~hal_tim_008~1`): while disabled, every
phase output holds its inactive state and accepted duty commands take effect on
the outputs at re-enable, and the reported state includes a disable forced by
the peripheral's break input.

Acceptance:
- Disabling holds all phase outputs inactive.
- Duty commands issued while disabled return true and take effect at re-enable.
- With no break asserted, the reported state matches the commanded state.
- The reported state reads disabled after a break-input assertion.

Covers:
- `sys~mc_004~1`

Needs: impl, test

### Per-phase output enable
`fw~io_bridge_004~1`

The driver shall enable or disable one phase's output independently, a disabled
phase holding both its gate lines at the inactive level while the other phases
keep driving.

Acceptance:
- Disabling one phase holds that phase's outputs inactive and leaves the other
  phases' outputs driving.
- Re-enabling the phase restores its output.
- A command on an out-of-range phase returns false.

Covers:
- `sys~mc_004~1`

Needs: impl, test

## Current and voltage sense

### Sense readout in engineering units
`fw~io_bridge_005~1`

The driver shall report each configured sense — the three phase currents,
the bus current, and the bus voltage — as

value = (V_pin − V_bias) / scale

with V_bias and scale the sense's configured bias and volts per unit, the
sample each reads per:

| Sense | Sample reported |
|---|---|
| Phase current | The most recently completed injected-sequence sample of that phase — U and V as sampled at the PWM crest, W as derived (`fw~io_bridge_006~1`) — never a regular-sequence sample; zero before the first |
| Bus current, bus voltage | The most recent regular-sequence sample of its ADC input |

returning false for a sense whose scale is zero, an out-of-range bridge or
phase, or an uninitialized driver.

Acceptance:
- A pin voltage of V_bias reads zero; a pin voltage of V_bias + scale reads
  one unit.
- A sense with zero scale returns false.
- A new injected sample changes the reported phase current at the next read;
  a new regular sample of the same input does not.
- A new regular sample changes the reported bus current at the next read.

Covers:
- `sys~mc_001~1`

Needs: impl, test

### Injected phase-current cycle
`fw~io_bridge_006~1`

The driver shall form each PWM cycle's phase-current triple from the
injected U and V samples whose timestamps fall within the configured pair
window — U and V in amps per `fw~io_bridge_005~1`'s law, W = −(U + V) — with
a sample arriving outside the window starting a new pair.

Acceptance:
- Over N PWM periods, N triples are formed, each from that period's
  samples.
- Two samples farther apart than the pair window form no triple.

Covers:
- `sys~mc_001~1`

Needs: impl, test

### Per-cycle callback
`fw~io_bridge_007~1`

The driver shall invoke a callback registered per bridge, with its
registered context, once per completed phase-current triple
(`fw~io_bridge_006~1`), in the interrupt context of the completing injected
conversion.

Acceptance:
- Over N completed triples the callback runs N times with the registered
  context, each after that triple is readable.

Covers:
- `sys~mc_001~1`

Needs: impl, test

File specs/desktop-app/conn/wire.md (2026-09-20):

---
status: draft
tags: [app, conn]
---

# Protocol client framing and envelope codec

The app side of the wire contract: COBS/CRC frames carrying protobuf
`Envelope`s, per the same format the firmware serves
([[../../firmware/conn/proto|proto]]).

### Frame codec
`app~conn_002~1`

The app shall carry each protocol payload as a frame per:

| Direction | Behavior |
|---|---|
| Transmit | Each payload encoded as a frame of the `fw~conn_proto_002~1` wire format |
| Receive | Received bytes split at `0x00` delimiters; each segment that COBS-decodes with a passing CRC-32 delivered in order; every other segment discarded |

Acceptance:

- A known payload encodes to the byte-exact reference frame of the
  `fw~conn_proto_002~1` format.
- A corrupted segment between two valid frames is discarded and both
  valid frames are delivered.
- Frames arriving split across arbitrary read boundaries are delivered
  whole and in order.

Covers:
- sys~conn_002~1

Needs: impl, test

### Envelope exchange
`app~conn_003~1`

The app shall exchange every protocol message as a schema `Envelope`
(`sys~conn_001~1`), assigning each transmitted request a `request_id`
unique among its outstanding requests and handling each received
envelope per:

| Received | Handling |
|---|---|
| A reply carrying an outstanding `request_id` | Resolved to that request — a `Response`'s verdict and `cause` (the `fw~conn_server_001~1` reply convention) delivered to the requester |
| A stream payload (log, telemetry, samples) | Dispatched to its consumer, independent of any request, and shed rather than held when the consumer falls behind — a shed `Samples` payload counted as a sample-time gap (`app~views_001~1`) |

Acceptance:

- Concurrent outstanding requests each resolve to their own reply by
  `request_id`.
- A `Response` with `accepted` clear delivers its `cause` to the
  requester.
- Stream envelopes decode and dispatch with no outstanding request.
- A reply queued behind a saturating sample stream resolves its request
  while the stream's consumer falls behind.

Covers:
- sys~conn_001~1

Needs: impl, test

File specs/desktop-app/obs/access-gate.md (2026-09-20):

---
status: draft
tags: [app, obs]
---

# Build-identity gate

### Build-identity gate
`app~obs_002~1`

The app shall enable signal trace, signal write, and memory read only
while the device's reported build identity (`sys~obs_003~1`) equals
the build identity of the loaded firmware ELF from which signals are
resolved (`app~obs_001~1`), presenting the gated capabilities as
unavailable otherwise while requests and telemetry remain available.

Acceptance:

- With the running build's ELF loaded, a watch install
  (`app~obs_003~1`) is issued and succeeds.
- A connection re-reads the loaded ELF file, so a file rebuilt since it
  was chosen gates by its current identity.
- With a different build's ELF loaded, the gated capabilities are
  unavailable, while a ping round trip and the telemetry view
  (`app~views_002~1`) continue.

Covers:
- sys~obs_004~1

Needs: impl, test

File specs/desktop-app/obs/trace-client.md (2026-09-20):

---
status: draft
tags: [app, obs]
---

# Trace client

The app side of the signal-trace stream: installing watch lists and
demultiplexing the returned `Samples` messages, against the firmware
services of [[../../firmware/conn/trace|trace]].

### Watch installation
`app~obs_003~1`

The app shall install the selected signals (`app~obs_001~1`) as one
`WatchRequest` of their resolved address, size, and per-signal period
entries — each period one PWM cycle, 1 ms, or 10 ms (`sys~obs_005~1`) —
presenting the reply: the `TraceStatus` budgets and usage on
acceptance, the rejection `cause` otherwise.

Acceptance:

- The selected signals arrive at the device as one watch list, and an
  accepted install presents the reported budgets and usage.
- A rejected install presents the cause, and the previously installed
  watch list's stream continues to render (`fw~conn_trace_002~1`).

Covers:
- sys~obs_005~1
- sys~obs_009~1

Needs: impl, test

### Samples demultiplexing
`app~obs_004~1`

The app shall demultiplex each received `Samples` message into
per-signal values by splitting its data bytes into `count` records,
assigning each record's bytes, in installed watch-list order, to the
signals of the message's period at cycle index `first_cycle` plus the
record's ordinal times the period, decoding each signal's bytes as its
resolved scalar type. Each cycle index maps to a sample time of 50 µs
per cycle.

Acceptance:

- With watches at the one-cycle, 1 ms, and 10 ms periods, every
  received message's records map to exactly the signals of its period,
  in list order, at cycle indices spaced by that period.
- A cycle-index gap yields values at exactly the received indices.
- A signal's bytes decode per its scalar type: width, signedness, and
  floating-point format.

Covers:
- sys~obs_005~1

Needs: impl, test

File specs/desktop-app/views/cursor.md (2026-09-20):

---
status: draft
tags: [app, views]
---

# Cursor

The plot widgets' pointing model: one cursor time for every plot
widget, the pointed-trace emphasis while paused, and the paused
comparison anchor with its preview and deltas.

## Cursor time

### Shared cursor
`app~views_005~1`

The app shall hold at most one cursor time — set by pointing at any
plot widget to the sample time nearest the pointer among that widget's
signals (the earlier of two equidistant) while that sample lies within
the greater of its signal's sample period and 4 px of the pointer and
inside the plotted range, and to the pointed time itself otherwise,
cleared when the pointer leaves every plot widget — each
plot widget marking a held time and listing, in its cursor readout,
its own signals' values at that time, rendered per the value
rendering table (`app~views_013~1`), a signal with no sample there
read out as absent.

Acceptance:

- Pointing at one plot widget places the cursor mark at the same time
  on every plot widget; leaving them clears every mark.
- Each plot's readout lists its signals' values at the held time; for
  a time inside a sample-time gap the readout states the absence.
- Pointing between two samples places the cursor on the nearer one, so
  a one-cycle signal's every sample is reachable beside a slower signal;
  pointing well inside a sample-time gap holds the pointed time.

See also: [[live-plot]], [[table]]

Covers:
- sys~arch_002~1

Needs: impl, test

## Pointed trace

### Pointed trace emphasis
`app~views_012~1`

While the timeline (`app~views_008~1`) is paused, the app shall
emphasize the pointed trace — the pointed-at plot widget's trace whose
rendered line lies nearest the pointer, within 40 px — rendering it at
twice its stroke width and marking its row in that widget's cursor
readout (`app~views_005~1`), the emphasis transient and the signal's
appearance (`app~views_011~1`) unchanged.

Acceptance:

- Moving the pointer near one of several traces thickens that trace
  and marks its readout row; moving nearer a different trace
  transfers both.
- With no rendered line within 40 px of the pointer, no trace is
  emphasized.

Covers:
- sys~arch_002~1

Needs: impl, test

## Comparison

### Comparison anchor
`app~views_017~1`

A plot widget shall hold at most one comparison anchor — a sample of
one of its signals, marked on that widget alone by a vertical line
at the anchor's time and a horizontal line at the anchor's value,
placed against the anchor signal's axis (`app~views_007~1`) — set
and released per the actions below, whose anchor modifier is the
platform's:

| Platform | Anchor modifier |
|---|---|
| Windows | Ctrl |
| macOS | Command |

| Action | Behavior |
|---|---|
| Anchor modifier + primary-button click, paused (`app~views_008~1`), with a pointed trace (`app~views_012~1`) | The pointed signal's sample nearest in time to the click, the earlier of two equidistant, becomes the anchor, replacing any prior one |
| Primary-button press and release moving under 6 px, within 8 px of either anchor line | The anchor releases |
| Resume (`app~views_009~1`) | The anchor releases |
| The anchor's signal leaves the widget (`app~views_004~1`) | The anchor releases |

Acceptance:

- Each action row produces its behavior.
- The lines mark only the anchoring widget; a second plot widget
  anchors independently.

Covers:
- sys~arch_002~1

Needs: impl, test

### Comparison deltas
`app~views_018~1`

While a plot widget holds a comparison anchor (`app~views_017~1`)
and a cursor time is held (`app~views_005~1`), the widget's cursor
readout shall report the deltas per:

| Delta | Shown |
|---|---|
| Time — the cursor time minus the anchor's time, in ms | In the readout |
| Value — the anchoring widget's pointed trace's (`app~views_012~1`) sample at the cursor time minus the anchor's value, rendered per `app~views_013~1` | On the pointed row, while the pointed signal is assigned the anchor signal's axis (`app~views_007~1`), both signals of integer or float scalar type (`app~obs_001~1`), and the pointed signal holds a sample at the cursor time |

Acceptance:

- With an anchor held, a cursor time set from any plot widget shows
  the anchoring widget's readout carrying the time delta.
- The anchoring widget's pointed trace on the anchor's axis shows
  the pointed row's value delta; a pointed trace on the other axis,
  a boolean or enumeration signal, and a cursor time where the
  pointed signal has no sample each show none.

Covers:
- sys~arch_002~1

Needs: impl, test

### Anchor preview
`app~views_019~1`

While the timeline is paused (`app~views_008~1`) and the anchor
modifier (`app~views_017~1`) is held with a pointed trace
(`app~views_012~1`), a plot widget shall show a candidate mark — a
horizontal line at the value of the pointed signal's sample nearest
the pointer in time, the earlier of two equidistant — the mark
following the pointer and the pointed trace.

Acceptance:

- With the anchor modifier held over a paused plot, the candidate
  mark sits at the nearest sample's value, moves with the pointer,
  and transfers with the pointed-trace emphasis.
- Releasing the anchor modifier removes the candidate mark and
  leaves the anchor state (`app~views_017~1`) as it was.

Covers:
- sys~arch_002~1

Needs: impl, test

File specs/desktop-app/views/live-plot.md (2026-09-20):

---
status: draft
tags: [app, views]
---

# Plot widget

The workspace's strip-chart widget ([[workspace]]).

## Rendering

### Live plot
`app~views_001~1`

A plot widget shall plot each of its signals' demultiplexed
values (`app~obs_004~1`) against their sample times as one trace
per signal in the signal's trace appearance (`app~views_011~1`),
extending as messages arrive, each gap-free run of sample times rendered
as one connected segment, its samples rendered per `app~views_014~1`.
A signal's marked gaps are bounded at 4096, the oldest coalescing
pairwise past that bound; the samples between two coalesced gaps are
not rendered.

Acceptance:

- A trace spanning a sample-time gap renders as separate segments with
  no line across the gap.
- Past the gap bound, the newest gaps still render as separate
  segments.

Covers:
- sys~arch_002~1

Needs: impl, test

### Trace decimation
`app~views_014~1`

A plot widget shall render each trace by pixel column of the plotted
X range, the samples rendered per:

| Samples in a pixel column | Rendered |
|---|---|
| More than two | The column's minimum and maximum samples |
| At most two | The column's samples |

Acceptance:

- A column holding more than two samples renders exactly its minimum
  and maximum samples, a single-sample spike preserved.
- Zooming while paused (`app~views_009~1`) until every column holds
  at most two samples renders every sample.

Covers:
- sys~arch_002~1

Needs: impl, test

## Axes

### Axis assignment and scaling
`app~views_007~1`

A plot widget shall render each signal against its assigned axis —
left or right, set per signal in the widget's axes configuration — the
widget rendering one Y axis per assigned side in use, each axis
carrying its own labels and ranging per its scale mode, also set in
the axes configuration:

| Scale mode | Axis range |
|---|---|
| Auto | The extent of the axis's signals' rendered values, following as they change |
| Manual | The minimum to maximum set in the axes configuration |

Acceptance:

- With all signals assigned to the same axis, a single labeled Y axis
  renders; with signals assigned to both, two axes render with
  distinct labels, each signal against its own.
- Values moving beyond an auto axis's range extend the axis; the same
  movement beyond a manual axis leaves its bounds unchanged.

Covers:
- sys~arch_002~1

Needs: impl, test

## Trace appearance

### Trace appearance
`app~views_011~1`

The app shall render a signal's trace, on every plot widget holding
it, per the signal's appearance, set in a widget's configuration menu:
its color, auto-assigned when the signal is first selected and stable
until changed; a solid, dotted, or dashed line; an optional dot at
each rendered sample (`app~views_014~1`); and an interpolation,
applied between consecutive rendered samples within each gap-free run
of sample times (`app~views_001~1`):

| Interpolation | Rendering |
|---|---|
| Zero-order hold | Each value holds as a step until the next sample |
| Linear | Straight segments between consecutive samples |
| Monotone cubic | A cubic curve through the samples that never overshoots them |

Acceptance:

- A changed line style, dots setting, and interpolation each render
  per their setting on every plot widget holding the signal.
- A changed color renders wherever the signal's trace color renders,
  the watch panel's row included (`app~views_010~1`).

Covers:
- sys~arch_002~1

Needs: impl, test

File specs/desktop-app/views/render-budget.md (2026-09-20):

---
status: draft
tags: [app, views]
---

# Render budget

### Render budget
`app~views_015~1`

Streaming the reference shape below for 60 s, the app shall render
within both budgets:

| Budget | Bound |
|---|---|
| Rendered frame rate | 60 rendered frames per second or above, averaged over every 1 s of the run |
| Rendered frame time | Every rendered frame completes within 33 ms |

| Reference-shape parameter | Value |
|---|---|
| Watch list (`app~obs_003~1`) | 8 signals: 4 at the one-cycle period and 4 at 10 ms |
| Plot widgets ([[workspace]]) | 4, each holding one one-cycle and one 10 ms signal |
| Display span (`app~views_008~1`) | 30 s |
| App window | 1920 × 1080 CSS px at a device pixel ratio of 1 |

Acceptance:

- Both budget rows hold, measured from the rendered-frame cadence
  across the full 60 s run of the reference shape.

See also: [[live-plot]]

Covers:
- sys~arch_002~1

Needs: impl, test

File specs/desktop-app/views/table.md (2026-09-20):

---
status: draft
tags: [app, views]
---

# Value table

### Value table
`app~views_006~1`

A table widget shall display one row per signal added to it — the
signal's name, its value per the mode below, rendered per
the value rendering table (`app~views_013~1`), its scalar type, and its
sample period, labeled per the period-label table of `app~views_010~1`:

| Mode | Value shown |
|---|---|
| No cursor time held | The latest streamed value, updating as samples arrive |
| A cursor time held (`app~views_005~1`) | The value at the cursor time, its absence stated for a time inside a sample-time gap |

Acceptance:

- A signal added to the table shows its newest streamed value beside
  the type and period it was resolved with.
- With a cursor time held (`app~views_005~1`), each row shows the
  value at that time.

See also: [[workspace]]

Covers:
- sys~arch_002~1

Needs: impl, test

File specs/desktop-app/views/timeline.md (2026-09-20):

---
status: draft
tags: [app, views]
---

# Timeline

The plot widgets' shared time base ([[live-plot]]): one span and one
live/paused mode for every plot widget, and the paused-range controls.

### Timeline
`app~views_008~1`

The app shall hold one plot timeline — a display span selected from
5 s, 10 s, 30 s, and 60 s, and a mode, live or paused — every plot
widget rendering the same X range per:

| Mode | X range |
|---|---|
| Live | The most recent span of the stream, following as samples arrive |
| Paused | Initially the whole span preceding the pause; thereafter the range set by the paused-range controls (`app~views_009~1`) |

While paused, the paused span's samples are retained for the whole
pause, and newly arriving samples (`app~obs_004~1`) are retained for
the first 120 s of the pause — a longer pause surfacing the unretained
interval as a sample-time gap on resume, at every sample period alike.

Acceptance:

- Selecting a span renders that duration across every plot widget's
  X axis.
- Pausing freezes every plot widget at the same range, and the whole
  paused span renders however long the pause holds.
- Resuming within 120 s renders the live span including the samples
  that arrived while paused; resuming later renders the unretained
  interval as a sample-time gap.
- A one-cycle signal fills a 60 s span, and resuming within 120 s
  renders the samples it received while paused.

See also: [[workspace]]

Covers:
- sys~arch_002~1

Needs: impl, test

### Paused range control
`app~views_009~1`

While the timeline (`app~views_008~1`) is paused, the app shall adjust
every plot widget's shared X range per the actions below, the range
bounded between 1 ms and the paused span:

| Action | Behavior |
|---|---|
| Vertical scroll over a plot widget, cursor time held | The range scales by a factor of 1.0015 per unit of wheel delta about the cursor time (`app~views_005~1`) |
| Vertical scroll over a plot widget, no cursor time held | The range scales by a factor of 1.0015 per unit of wheel delta about its center |
| Horizontal scroll over a plot widget | The range pans at its scale |
| Primary-button horizontal drag across a plot widget's canvas | Every plot widget's range becomes the dragged X extent |
| Resume | The timeline returns to live (`app~views_008~1`) |

Acceptance:

- A wheel step over one plot widget rescales the range on every plot
  widget, about the held cursor time or, with none held, the range
  center.
- Panning stops at the paused span's edges, zooming out at the span,
  and zooming in at 1 ms; a step into any bound leaves the range
  unchanged.
- A horizontal drag on one plot widget sets every plot widget's range
  to the dragged extent.

Covers:
- sys~arch_002~1

Needs: impl, test

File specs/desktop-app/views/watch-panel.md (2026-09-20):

---
status: draft
tags: [app, views]
---

# Watch panel

### Watch panel
`app~views_010~1`

The app shall list each signal on the watch list in the signal
picker's watch panel — a row of the signal's trace color, name,
sample period, and latest streamed value, the value rendered per the
value rendering table (`app~views_013~1`) — the period selectable and
the signal removable in the row, either edit applied through the
watch installation (`app~obs_003~1`), each period labeled per:

| Period | Label |
|---|---|
| 1 cycle | 20 kHz |
| 20 cycles | 1 ms |
| 200 cycles | 10 ms |

Acceptance:

- A row appears when its signal joins the watch list and leaves when
  the signal is unwatched, its value cell tracking the newest sample.
- Editing a row's period, and removing a row, each reach the device
  as one recommitted watch list (`app~obs_003~1`).

See also: [[../obs/signal-picker|signal-picker]], [[table]]

Covers:
- sys~arch_002~1

Needs: impl, test

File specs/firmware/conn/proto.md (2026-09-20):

---
status: draft
tags: [firmware, conn, proto, driver]
---

# Protocol framing and schema

The protocol stack over the serial byte stream: messages are defined in
protocol-buffer schemas — the reusable framework schema at
`sw/lib/c/shared/proto/`, importing the board schema at `sw/proto/` for
the envelope's fixed-name board payloads — and cross the wire as
COBS-delimited, CRC-validated frames carried by the `IO_COBSFrame`
io-layer frame driver over an `IO_serial` channel ([[serial]]).

## Schema

### Envelope schema
`fw~conn_proto_001~1`

The firmware shall exchange every protocol message as an `Envelope` — a
`request_id` field and a `oneof` of all protocol payload types —
reporting failure for received bytes that do not decode as an
`Envelope`.

Acceptance:
- An `Envelope` carrying each payload type encodes and decodes back to
  identical field values.
- An `Envelope` assembled around an already-encoded payload is
  byte-identical to the `Envelope` encoded whole.
- Decoding a truncated `Envelope` encoding reports failure.

Covers:
- sys~conn_001~1

Needs: impl, test

## Frame codec

### Frame format
`fw~conn_proto_002~1`

Each frame on the wire shall consist of:

| Field | Content |
|---|---|
| Leading delimiter | `0x00` |
| Body | COBS encoding of: the encoded `Envelope` followed by the IEEE 802.3 CRC-32 of the encoded `Envelope`, little-endian |
| Trailing delimiter | `0x00` |

Acceptance:
- A known `Envelope` encodes to a byte-exact reference frame vector.
- The body contains no `0x00` byte.
- A frame encoded into a caller's buffer is byte-identical to the
  transmitted one; a buffer too short for it takes nothing.

Covers:
- sys~conn_002~1

Needs: impl, test

## Driver configuration and lifecycle

### Frame driver initialization and configuration validation
`fw~conn_proto_003~1`

The frame driver shall validate the supplied configuration before use
and initialize every configured channel, returning false if the
configuration is rejected by any of:

| Element | Rejected when |
|---|---|
| Config | The config pointer or its channel array is NULL, or the channel count exceeds the available frame channels. |
| Channel | A channel names an unavailable backing serial channel, or declares a maximum frame length of zero. |

Acceptance:
- A valid config initializes every channel and returns true.
- Each rejection condition returns false.

Covers:
- sys~conn_002~1

Needs: impl, test

## Data transfer

### Whole-frame transmission
`fw~conn_proto_004~1`

The server shall hand a frame to the serial channel only when the
channel's free transmit capacity (`fw~conn_serial_006~1`), less what the
pass already holds (`fw~conn_server_006~1`), holds the entire frame,
accepted frames leaving in order and a frame that does not fit reported
dropped.

Acceptance:
- A frame within the remaining capacity leaves in full, in order with
  the pass's earlier frames.
- A frame exceeding the remaining capacity is dropped whole — no bytes
  of it reach the transport — and reported dropped.

Covers:
- sys~conn_002~1

Needs: impl, test

### Frame reception and resynchronization
`fw~conn_proto_005~1`

On a channel, the frame driver shall split bytes received from the
backing serial channel into `0x00`-separated segments and handle each
segment per:

| Segment | Handling |
|---|---|
| COBS-decodes with a passing CRC, within the channel's configured maximum frame length (`fw~conn_proto_003~1`) | Delivered to the consumer, in arrival order |
| Empty | Skipped |
| COBS error, CRC mismatch, or over the maximum frame length | Discarded |

Acceptance:
- Frames arriving back-to-back are delivered in order.
- A corrupted segment is discarded and the following valid frame is
  delivered.
- Bytes exceeding the maximum frame length with no delimiter are
  discarded and the next valid frame is delivered.

Covers:
- sys~conn_002~1

Needs: impl, test

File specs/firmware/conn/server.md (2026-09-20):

---
status: draft
tags: [firmware, conn, server]
---

# Request server

The app_server module: envelope dispatch over the frame driver
([[proto]]), answering each received envelope with a correlated reply,
applying board commands to the shared motor-control request state, and
serving the trace services ([[trace]]) — watch streaming, memory read
and write, and the trace capability report.

### Request acknowledgement
`fw~conn_server_001~1`

The firmware shall answer every received envelope
(`fw~conn_proto_001~1`) with a reply envelope carrying the received
`request_id`, whose payload follows:

| Received envelope | Reply payload |
|---|---|
| A request producing a result | The result payload (e.g. `Identity` for `IdentityRequest`) |
| A request succeeding without a result | `Response` with `accepted` set |
| A rejected request, or a payload that is not a recognized request | `Response` with `accepted` clear and `cause` naming the reason |

Acceptance:
- A `PingRequest` receives a `Response` with `accepted` set, carrying
  the request's `request_id`.
- A request received while the sample stream (`fw~conn_trace_009~1`)
  holds the transmit capacity is answered within 2 ms.
- An envelope bearing no recognized request payload receives a
  `Response` with `accepted` clear and a non-empty `cause`.

Covers:
- sys~conn_003~1

Needs: impl, test

## Board commands

`board.Request` commands act on the request state shared with the
on-device controls (`sys~ops_002~1`). A `board.Mode` value is either
`MODE_OFF` — the bridge-disable request of `fw~mc_006~1` — or names a
commutation method (`sys~mc_005~1`).

### SetMode handling
`fw~conn_server_002~1`

An accepted `SetMode` shall request the commanded state of the motor
control application — `MODE_OFF` the bridge disabled, a method value
the bridge enabled running that method — rejecting the command when:

| Rejected when |
|---------------|
| The value names no `board.Mode` member |
| A method other than the active one is named while the bridge is enabled (`sys~mc_005~1`) |
| A method is named while a fault is latched (`fw~safety_001~1`, `fw~safety_002~1`) |

Acceptance:
- With the bridge disabled and no fault latched, a method value is
  accepted and the bridge enable is requested with that method;
  `MODE_OFF` is accepted in every state.
- Each rejection condition rejects the command, the requested state
  unchanged.

Covers:
- sys~ops_002~1

Needs: impl, test

### SetVelocity handling
`fw~conn_server_003~1`

An accepted `SetVelocity` shall become the shared speed target
(`sys~ops_002~1`), rejecting the command when the value is not finite
or its magnitude exceeds the configured maximum (`fw~mc_008~1`).

Acceptance:
- A finite value within the maximum becomes the speed target.
- A non-finite value and an over-maximum value are each rejected, the
  target unchanged.

Covers:
- sys~ops_002~1

Needs: impl, test

### ClearFault handling
`fw~conn_server_004~1`

An accepted `ClearFault` shall perform the fault-clear action
(`fw~safety_001~1`, `fw~safety_002~1`), the command accepted with or
without a fault latched.

Acceptance:
- With a fault latched, an accepted `ClearFault` releases it.
- With no fault latched, `ClearFault` is accepted.

Covers:
- sys~safety_001~1

Needs: impl, test

## Diagnostics

### Link throughput test
`fw~conn_server_005~1`

An accepted `LinkTestRequest` shall stream `LinkTestFrame` messages —
sequence numbers 0 through the requested count minus 1, each payload
of the requested size with byte $i$ equal to $(\text{seq} + i) \bmod
256$ — as many per millisecond as the pass accepts whole frames
(`fw~conn_server_006~1`), a running test abandoned when the serial channel
loses the host connection (`fw~conn_serial_005~1`), the request rejected
when:

| Rejected when |
|---------------|
| The payload size is outside 1..256 bytes |
| The frame count is outside 1..1000000 |
| A test is in progress |

Acceptance:
- An accepted request yields exactly the requested count of frames with
  consecutive sequence numbers and the pattern payload.
- A request during a test is rejected; a request after the count is
  reached is accepted.
- A disconnect ends a running test; a request after reconnect is
  accepted with sequence numbers restarting at 0.
- Each rejection condition rejects the request.

Covers:
- sys~conn_004~1

Needs: impl, test

### Pass transmission
`fw~conn_server_006~1`

The server shall hand each millisecond pass's frames — replies,
telemetry, log, samples, and link-test frames — to the serial channel
as one write, framing each (`fw~conn_proto_002~1`) into a pass buffer
of 768 bytes — a pass outgrowing the buffer taking one further write per
fill — a frame taken whole or not at all when the channel's free
transmit capacity (`fw~conn_serial_006~1`), less what the pass already
holds, cannot hold it.

Acceptance:

- A pass that produces several frames within the buffer reaches the
  serial channel as one write carrying them in order.
- A frame the channel's remaining capacity cannot hold is not written;
  the pass's earlier frames still leave.

Covers:
- sys~conn_002~1

Needs: impl, test

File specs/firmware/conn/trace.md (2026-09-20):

---
status: draft
tags: [firmware, conn, trace, server]
---

# Signal trace services

The trace services of the app_server module ([[server]]): a host-set
watch list of memory spans sampled at per-entry periods in the PWM
cycle callback and streamed as `Samples` messages, one-shot memory
reads and writes, and the trace capability report.

## Configuration

### Trace resource configuration
`fw~conn_trace_001~1`

The server shall take the trace services' resources from its
configuration — the readable memory regions, the writable memory
regions, the watch capacity in entries, the sample-RAM budget in bytes
per millisecond, and the link budget in bytes per second — returning
false at initialization when the configuration is rejected by any of:

| Element | Rejected when |
|---|---|
| Readable regions | The set is empty, or a region has zero length |
| Writable regions | A region has zero length |
| Watch capacity | Zero |
| Budgets | The sample-RAM budget or the link budget is zero |

Acceptance:

- A configuration declaring a readable region and nonzero budgets
  initializes, returning true.
- Each rejection condition returns false.

Covers:
- sys~obs_005~1

Needs: impl, test

## Watch list

### Watch-list admission
`fw~conn_trace_002~1`

A `WatchRequest` shall replace the active watch list in full when
accepted and leave it unchanged when rejected, rejecting the request
when:

| Element | Rejected when |
|---|---|
| Entry span | Not contained in one readable region (`fw~conn_trace_001~1`) |
| Entry size | Outside 1..8 bytes |
| Entry period | Not 1, 20, or 200 PWM cycles |
| Entry count | Exceeds the watch capacity (`fw~conn_trace_001~1`) |
| Samples fit | Any $S_g$ exceeds the 256-byte `Samples` data capacity (`fw~conn_trace_005~1`) |
| RAM usage | $u$ exceeds the sample-RAM budget (`fw~conn_trace_001~1`) |
| Link rate | $r$ exceeds the link budget (`fw~conn_trace_001~1`) |

where, over the requested entries with sizes $s_i$ bytes grouped by
period into groups $g$ of period $c_g$ cycles, record size
$S_g = \sum_{i \in g} s_i$, record rate $f_g = 20000 / c_g$ per second,
and records per millisecond $n_g = \max(1,\ 20 / c_g)$:

$$u = \sum_g n_g \,(4 + S_g) \quad \text{[bytes per millisecond]}$$

$$r = \sum_g \Bigl( S_g f_g + W \cdot m_g \Bigr), \quad
m_g = \min\Bigl(f_g,\ \max\bigl(1000,\ f_g S_g / 256\bigr)\Bigr)
\quad \text{[bytes per second]}$$

with $W$ the per-message wire overhead of `fw~conn_trace_005~1`, $m_g$
the group's message rate per `fw~conn_trace_009~1`, and an empty list
having $u = 0$ and $r = 0$.

The emission tick and the cycle boundary are independent, so a one-cycle
group captures 21 records between two emissions whenever they drift past
each other: a list admitted at exactly the sample-RAM budget takes
periodic single-record gaps (`fw~conn_trace_004~1`).

Acceptance:

- An accepted request replaces the active list in full: sampling
  (`fw~conn_trace_004~1`) follows only the new list.
- A rejected request leaves the active list unchanged: sampling
  continues per the prior list.
- Each rejection condition rejects the request.
- A list whose $u$ equals the sample-RAM budget, and one whose $r$
  equals the link budget, are each accepted.

Covers:
- sys~obs_005~1

Needs: impl, test

### Watch-list clear on disconnect
`fw~conn_trace_003~1`

The server shall clear the active watch list when its serial channel
loses the host connection (`fw~conn_serial_005~1`).

Acceptance:

- With a watch list active, a disconnect followed by a reconnect
  produces no `Samples` message until a new `WatchRequest` is accepted.
- After the reconnect, the reported usage (`fw~conn_trace_006~1`) is
  zero.

Covers:
- sys~obs_005~1

Needs: impl, test

## Sampling and streaming

### Watch sampling
`fw~conn_trace_004~1`

While the active watch list (`fw~conn_trace_002~1`) is non-empty, the
server shall sample it in the bridge cycle callback
(`fw~io_bridge_007~1`), after that cycle's commutation step
(`fw~mc_015~1`), per:

| Behavior | Detail |
|---|---|
| Cycle index | Sampling advances a 32-bit PWM-cycle index each callback, restarted at zero when a list installs, buffered samples of the prior list discarded |
| Capture | Each cycle captures every group that is due — a group of period $c$ cycles and offset $k$ is due when $(\text{index} - k) \bmod c = 0$ — the group's entries captured as one coherent snapshot into one buffered record |
| Overflow | A record that does not fit in the free space of the sample buffer — its size the sample-RAM budget (`fw~conn_trace_001~1`) — is skipped whole, and skipping holds until the buffer has drained to half the budget, so a loss is one contiguous gap |

| Group period $c$ | Offset $k$ |
|---|---|
| 1 cycle | 0 |
| 20 cycles (1 ms) | 1 |
| 200 cycles (10 ms) | 2 |

Acceptance:

- With a one-cycle entry, consecutive emitted records carry consecutive
  cycle indices, each with the entry's bytes.
- Entries at 1, 20, and 200 cycles appear in exactly the cycles their
  group's offset and period select.
- Two locations the firmware updates together within a cycle arrive
  mutually consistent in every capture.
- After a list installs, the first emitted record of each group carries
  that group's offset as its cycle index, and no prior-list record
  follows it.
- With emission stalled long enough to fill the sample buffer, emitted
  cycle indices jump past the skipped records and every emitted record
  holds a complete capture.
- Once a record is skipped, no record is admitted until the buffer has
  drained to half the budget; the records then admitted form one
  gap-free run.

Covers:
- sys~obs_005~1

Needs: impl, test

### Sample emission
`fw~conn_trace_009~1`

Each millisecond, the server shall emit each group's buffered records
(`fw~conn_trace_004~1`) in capture order as `Samples` messages
(`fw~conn_trace_005~1`), consecutive records of one group whose cycle
indices step by its period sharing a message up to its data capacity,
a message starting only where the transmit capacity holds a full one
(records otherwise staying buffered), each emission taking only the
records buffered and the capacity present at its start, and leaving one
reply frame of transmit capacity (`fw~conn_server_001~1`) unused.

Acceptance:

- A one-cycle group with 16-byte records reaches the host as messages
  of up to 16 records, with no record held longer than 2 ms.
- A 10 ms group's records each arrive in their own message.
- A one-cycle group's records buffered across a 3 ms emission stall
  arrive in the next emission, in capture order.
- With transmit capacity for less than a full message, no message
  leaves; the buffered records arrive whole once capacity returns.

Covers:
- sys~obs_005~1

Needs: impl, test
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

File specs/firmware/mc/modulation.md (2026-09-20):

---
status: draft
tags: [firmware, mc, app, driver]
---

# Frame transforms and space-vector modulation

Pure functions shared by the commutation methods: the transforms between
phase, stationary (α, β), and rotor (d, q) quantities, and the space-vector
modulator that turns a stationary-frame voltage command into three
per-phase duties.
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

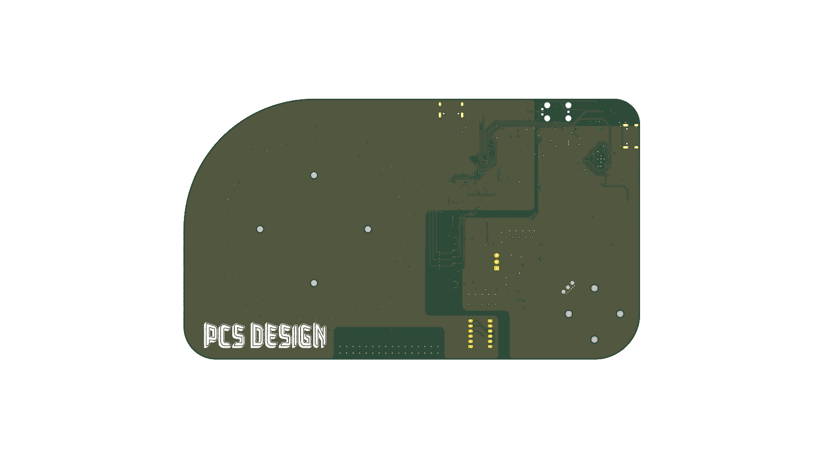
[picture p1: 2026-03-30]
hw/bldc_render_bottom.png

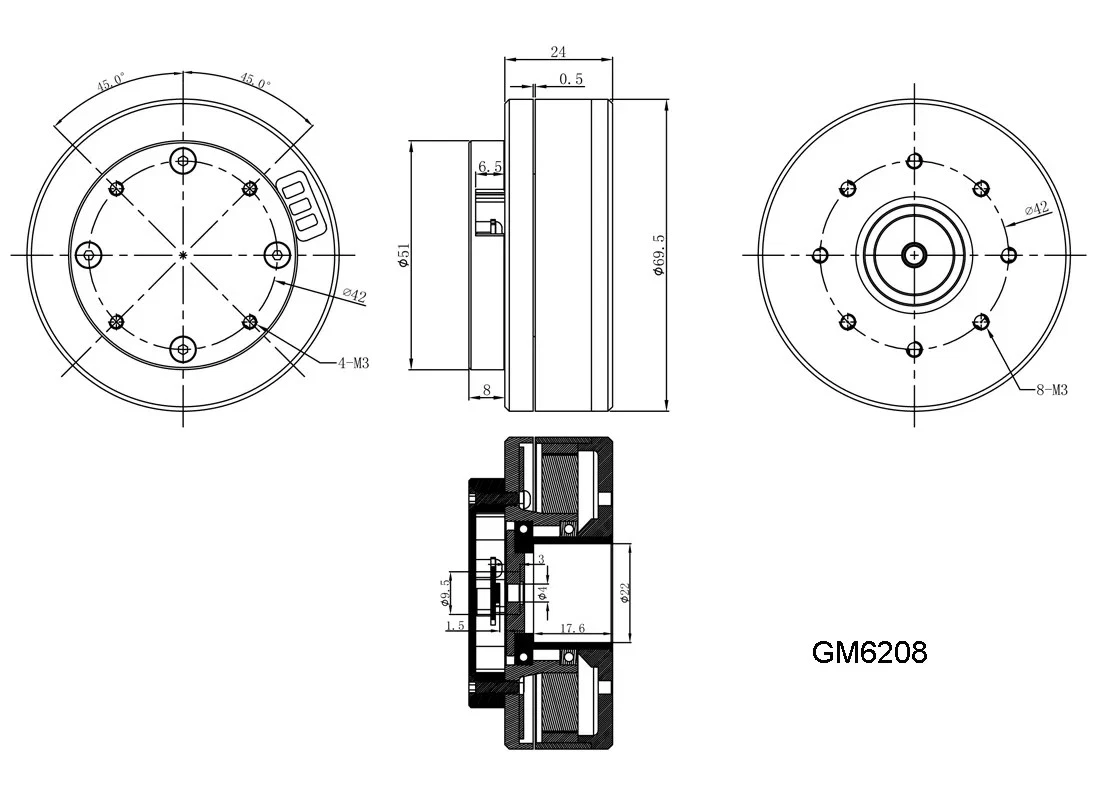
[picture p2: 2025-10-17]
datasheets/gm6208_dimensions.webp

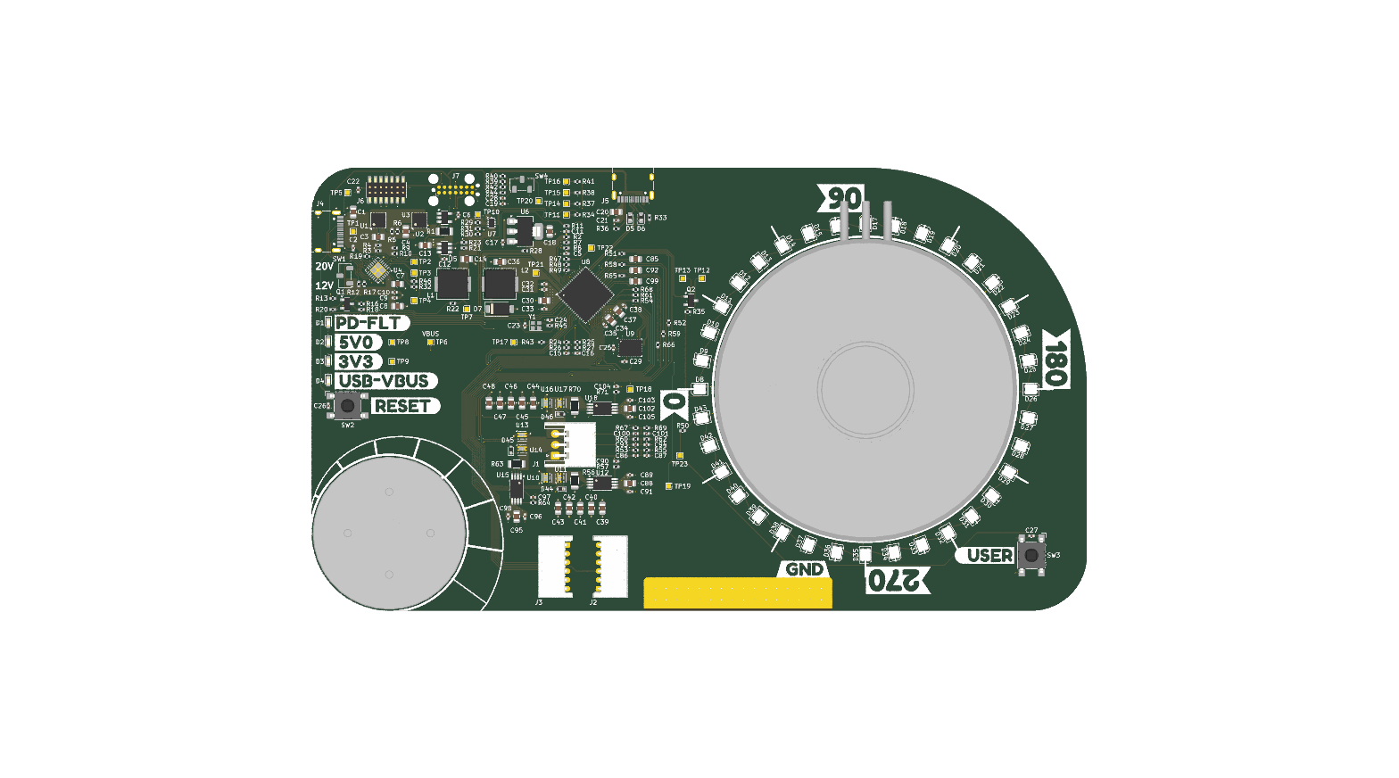
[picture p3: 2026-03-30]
hw/bldc_render_top.png

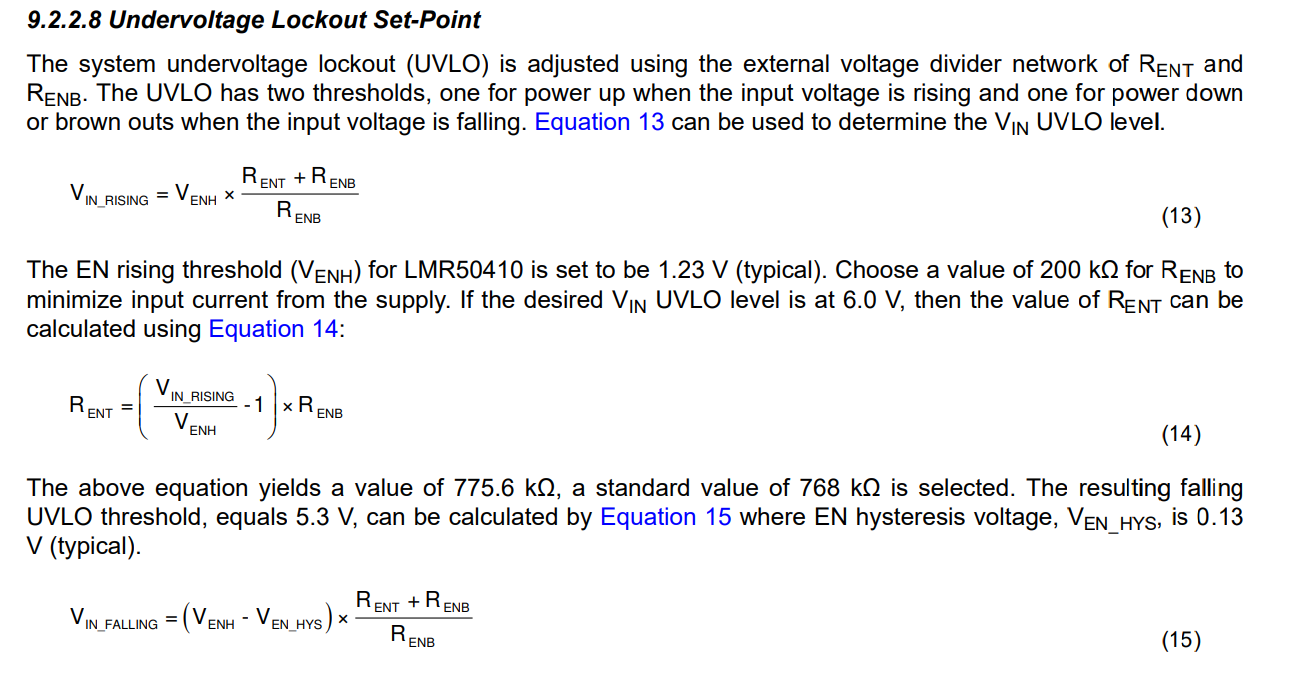
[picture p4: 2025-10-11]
datasheets/buck_uvlo.PNG

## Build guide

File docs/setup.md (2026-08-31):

# First-time setup

This document is the single source of truth for setting up a development
environment for `pcs_bldc`. Run `./setup.sh` from the repo root for the
automated parts; this document describes what it checks, what it sets up,
and what to do for missing prerequisites.

## Supported platforms

- **Windows** (primary)
- **macOS** (primary)

Linux is not currently targeted and may be added later. The setup script
detects the OS via `uname -s` and adapts.

## Prerequisites

These tools are not installed automatically — `setup.sh` checks for them
and prints install instructions if they are missing.

| Tool | Version | Required for | Windows install | macOS install |
|---|---|---|---|---|
| Java JDK  | 17 or later | OFT (all work) | `winget install Microsoft.OpenJDK.21` | `brew install --cask temurin@21` |
| Python | 3.10 or later | firmware builds (protobuf bindings), SIL, analysis | `winget install Python.Python.3.12` | `brew install python@3.12` |
| CMake | recent | firmware / SIL builds | `winget install Kitware.CMake` | `brew install cmake` |
| Ninja | recent | `tools/build_*.sh` | `winget install Ninja-build.Ninja` | `brew install ninja` |
| ARM GCC | recent | embedded firmware builds | [ARM GNU toolchain downloads](https://developer.arm.com/downloads/-/arm-gnu-toolchain-downloads) | `brew install --cask gcc-arm-embedded` |
| Rust | stable | desktop app (`sw/gui`), SIL harness, Rust crates | [rustup.rs](https://rustup.rs) | [rustup.rs](https://rustup.rs) |
| KiCad | 10.x | **HW design only** | `winget install KiCad.KiCad` | `brew install --cask kicad` |
| Git | recent | (cloning) | `winget install Git.Git` | preinstalled / `brew install git` |

Java and Python block `setup.sh`; CMake, Ninja, ARM GCC, and KiCad are
warn-only (each gates only its own workflow). Rust is not checked by
`setup.sh` — install it if you touch `sw/gui`, `sw/sil`, or `sw/lib/rust`.

**Python is a firmware-build prerequisite**: the firmware configure
generates its protocol bindings with the venv's nanopb generator and
fails without `.venv` (the protoc it invokes is bundled by
`grpcio-tools`; both come from `requirements.txt` via `setup.sh`).

**KiCad is required only for hardware design work.** If you are only
contributing to firmware, SIL infrastructure, analysis notebooks, or the
desktop tooling, you can ignore a missing-KiCad warning from `setup.sh`
and proceed. The setup script warns rather than blocks when KiCad is
missing.

The KiCad detection in `setup.sh` is version-agnostic: it globs
`C:\Program Files\KiCad\<version>\bin\kicad-cli.exe` (Windows) or uses
the standard `/Applications/KiCad/KiCad.app` location (macOS) and picks
the newest installed version. The hardware files in `hw/` are currently
maintained in **KiCad 10**.

After installing fundamental tools (especially Java) on Windows via
`winget`, restart your shell so `PATH` picks up the new entries. The OFT
wrapper has a fallback for the same-session case, but everything else
assumes `java` is on `PATH`.

## What `setup.sh` does

Once prerequisites are present, `./setup.sh` is idempotent and:

1. Detects the OS and verifies prereqs (Java, Python, KiCad, ARM GCC,
   CMake, Ninja).
2. Downloads and SHA256-verifies the project-pinned OpenFastTrace JAR via
   [`tools/oft/install.sh`](../tools/oft/install.sh).
3. Creates `.venv/` if it does not exist and installs Python dependencies
   from [`requirements.txt`](../requirements.txt).

Re-running is safe; already-installed steps are skipped where possible.

## Verifying the install

Smoke-test the OpenFastTrace traceability tool:

```bash
./tools/oft/oft.sh trace tools/oft/_smoketest/
```

Expected output: `ok - 5 total`, exit code 0.

The `_smoketest/` directory contains one `sys~`, one `sw~`, one `impl`,
and two `test` items that fully cover each other — useful as a working
example of the spec system described in [`spec-system.md`](spec-system.md).

## Coming later

Setup steps that will be added as the project grows:

- **Docker / devcontainer** — for fully reproducible builds in CI.

## Troubleshooting

- **`java: command not found` on Windows after `winget install`.** `PATH`
  is captured at shell start; restart your shell. The OFT wrapper
  ([`tools/oft/oft.sh`](../tools/oft/oft.sh)) will fall back to
  `C:\Program Files\Microsoft\jdk-*-hotspot\` in the meantime.
- **`pip` complains about missing modules in `.venv` on Windows.**
  Activate the venv (`.venv/Scripts/activate`) or invoke pip directly
  (`.venv/Scripts/pip.exe`).
- **`kicad-cli` not on `PATH` on Windows.** This is normal; KiCad does
  not add its CLI to `PATH` by default. Use the absolute path under
  `/c/Program Files/KiCad/<version>/bin/kicad-cli.exe` (e.g.
  `/c/Program Files/KiCad/10.0/bin/kicad-cli.exe`); `setup.sh` and
  [`CLAUDE.md`](../CLAUDE.md) detect this path automatically.

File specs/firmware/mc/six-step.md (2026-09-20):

---
status: draft
tags: [firmware, mc, app, driver]
---

# Six-step encoder-commutated method

Sensored block commutation: the rotor electrical angle — motor shaft angle
corrected by a captured alignment offset and scaled by the pole-pair
count — selects which two phases conduct; the third floats.

See also: [[motor-control-application]] (fw~mc_015~1 runs this method's
step each PWM cycle), [[bridge]] (`fw~io_bridge_002` duties; per-phase
float via `fw~io_bridge_004` output disable).

### Six-step commutation
`fw~mc_011~1`

While active with the bridge enabled, the six-step method shall apply the
commutation pattern of the sector containing the rotor electrical angle —
derived from the motor shaft angle, the stored alignment offset
(fw~mc_012~1), and the configured pole-pair count — advanced by the
configured lead angle in the direction of the signed speed target, at a
duty proportional to the target magnitude clamped to the configured
maximum:

| Sector (electrical) | Duty d | Duty 0 | Floating |
|---|---|---|---|
| 0°–60° | U | V | W |
| 60°–120° | U | W | V |
| 120°–180°  | V | W | U |
| 180°–240°  | V | U | W |
| 240°–300°  | W | U | V |
| 300°–360°  | W | V | U |

Acceptance:
- In each sector, the table row's duty-d phase and duty-0 phase are driven
  and the floating phase's outputs are disabled.
- Reversing the target sign reverses the sector progression.
- The applied duty is proportional to the target magnitude, clamped to the
  configured maximum.

Covers:
- sys~mc_005~1

Needs: impl, test

### Alignment offset capture
`fw~mc_012~1`

On its first bridge enable after power-up, the six-step method shall drive
the 0°–60° sector pattern at the configured alignment duty for the
configured dwell time, then capture the motor shaft angle as the alignment
offset on which all subsequent enables commutate.

Acceptance:
- The first enable applies the alignment pattern for the dwell time, then
  captures the offset, then begins commutation.
- Subsequent enables commutate immediately with the stored offset.
- A zero speed target during commutation does not re-trigger alignment; the
  stored offset is retained.

Covers:
- sys~mc_005~1

Needs: impl, test

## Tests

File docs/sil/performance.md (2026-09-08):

# Performance architecture

Cross-cutting design doc. The sim must run **many× faster than realtime on a
normal desktop** — no supercomputer. This captures the cost model, the levers,
and the seams we bake in from the start so the target stays reachable.

---

## 1. Cost model

Base `dt` is fine (a few µs), so 1 sim-second = ~10⁵–10⁶ ticks. To run **N×**
realtime, each tick must cost `dt/N` (e.g. `dt=2µs`, 50× → **40 ns/tick**). The
whole game: **make the common tick ≈ one ODE step, and make ticks rarer.**
Per-tick cost centers:

1. continuous-model ODE integration — *every* tick
2. framework↔firmware boundary crossing — *every advance*
3. firmware execution + task context switches — *firmware-active ticks*
4. historian change-detection — *trace-everything*
5. route propagation

## 2. Lever 1 — single-threaded cooperative fibers (the foundation)

**One OS thread runs everything.** The framework is the "main" context; each
FreeRTOS task is a **fiber** (its own stack); the scheduler picks the next fiber;
`portYIELD` = a fiber swap (~30–100 ns). "Advance the firmware" swaps into the
firmware; quiescence (the idle fiber) swaps back. **No OS threads, no
cross-thread signaling.**

This replaces an earlier two-thread + OS-thread-host-port design, which was a
performance trap: OS-thread context switches are ~1–5 µs and a two-thread
framework↔firmware handshake signals ~1 µs/tick — at 10⁵–10⁶ ticks/s that alone
can be **slower than realtime**. Fibers are ~50× cheaper *and* strictly more
deterministic. Foundational and hard to retrofit → **build it this way from the
start.** See [`freertos-tick.md`](freertos-tick.md) (D1).

## 3. Lever 2 — gate discrete work to when it's needed

Between control activations (e.g. 24 of every 25 ticks if control is 50 µs and
`dt`=2 µs) the firmware doesn't run and the PWM command is held, so the **only**
necessary work is integrating the continuous (dynamic) models with held inputs.
Everything else gates to firmware-active ticks:

- firmware execution, route propagation, historian scan → only when firmware ran
- **algebraic (stateless) models** (sensors, encoder, inverter) → evaluated
  **on-demand** when their output is read, not every tick
- **dynamic (stateful) models** (motor electrical + mechanical) → integrate every
  tick

Steady-state per-tick cost collapses to ≈ one ODE step. Free to design in now,
painful to bolt on later.

## 4. Lever 3 — fewer ticks via better integrators (couples D6)

Base `dt` is set by model *stability*. An **unconditionally-stable** integrator
(semi-implicit / exponential for the stiff electrical `di/dt`) makes `dt`
accuracy-limited, not stability-limited → potentially **~10× fewer ticks**. Also
avoid per-tick transcendentals — update the Park/Clarke `sin/cos` **incrementally**
(rotate by the angular delta) instead of calling `sin/cos` each tick. Tick count
is the master knob; the integrator is model-owned ([`inverter-timestep.md`](inverter-timestep.md))
so it can be upgraded without touching the engine.

## 5. Lever 4 — historian: gate + dirty-page tracking

Trace-everything ([`signal-trace.md`](signal-trace.md)) must not scan thousands
of statics every tick.

- **Gate on "firmware ran this tick"** (free): firmware statics only change when
  firmware executed, so skip the scan on idle ticks.
- **Dirty-page tracking:** mark the firmware's `.data`/`.bss` **read-only** before
  a burst; a fault handler (Windows **VEH** / macOS **mach exception**) marks
  written pages dirty and un-protects them; after the burst, scan only the traced
  variables on **dirty pages** (~100× less). `GetWriteWatch` does *not* apply
  (loader-mapped memory), so it's protect-and-fault.

Bake the **pluggable change-detector seam** now (naive-scan ↔ dirty-page); gate
first, add dirty-tracking when it profiles hot.

**The whole-namespace mirror sweep is exactly this workload.** The firmware
member now mirrors every traceable cvar leaf memory→table each tick (naive scan,
[`signal-trace.md`](signal-trace.md) §4) — this is what the dirty-page lever will
optimize. Two mitigations already hold: the sweep reads through **pre-resolved
address/type handles** (cached at enable — no per-tick DWARF re-resolution), and
the in-sync **flush is sparse** (only the command-dirtied cvars, via the
State Table dirty set, never the whole namespace). Measured on the pcs_bldc DLL:
**~430 cvar leaves** swept per tick (the built-in array-size exclusion drops the
task stacks / heap / 512-byte buffers that would otherwise dominate).
Phase-isolated measurement (§11) shows the **sweep dominates a full engine step**:
the bare firmware advance is only ~4 µs, while the whole-namespace mirror +
flush + routes add ~45 µs on top — so **gated / dirty-page scanning is the
highest-value next lever**, exactly as this section predicts.

**Implemented — Tier 1 + Tier 2 (2026-07-09).** The naive per-leaf scan is
replaced by two composed optimizations, taking the full step **49 → ~9 µs
(>100× realtime)**:

- **Tier 1 — shadow-snapshot `memcmp` sweep** (`backend.rs` / `FirmwareMember`).
  At enable, the resolved leaves are sorted by address and grouped into contiguous
  **ranges** (merged across gaps ≤64 B so a struct's traced fields share a range),
  each subdivided into 64 B **chunks** with a chunk→leaf map and a per-range
  **shadow buffer**. Per tick, each range is `memcmp`d against its shadow *directly
  against live memory* (no copy); only a **changed** range is pulled in and
  localized chunk-by-chunk, re-decoding just the leaves in changed chunks (a leaf
  straddling a chunk edge is listed under every chunk it overlaps). The shadow
  mirrors **memory** — updated even where the table dedups the
  record — and the first sweep after (re)enable is cold (full baseline). This is
  the gate this section called for: work is now **O(changed bytes)**, not
  O(leaves). (The address ranges derive strictly from resolved leaf `addr+size`,
  so every byte read lies within a real firmware static; see the `read_range`
  SAFETY note.)
- **Tier 2 — dense-index State Table fast lane** (`state_table.rs`). The
  `IndexSet<SignalId>` already yields a stable dense index per signal; the hot
  per-signal storage (`current`, `changes`, resolved `epsilon`, dirty/
  evicted membership) migrated to index-keyed `Vec`/`HashSet<usize>` storage, and
  the changed-leaf decode path, route endpoints, and port-cache fill resolve their
  index **once** (at registration / first propagation) and call the crate-internal
  `record_mirror_at` / `record_at` / `current_value_at` — so no hot path hashes a
  `SignalId` string. The public string-keyed API is unchanged (thin
  resolve-then-delegate wrappers).

Dirty-page tracking (the remaining §5 lever) is now **lower priority** — the
shadow `memcmp` already reads only the mirrored bytes and re-decodes only the
changed ones; dirty-page protect-and-fault would mainly cut the residual
whole-shadow `memcmp` traffic, a smaller win from here.

## 6. Lever 5 — zero-alloc hot loop

No `malloc` per tick. Preallocate everything; historian append = bump-pointer
into **chunked per-signal columnar buffers**; routes as flat `(src, dst, size)`
arrays iterated with `memcpy`. Steady-state allocation-free. Easy to design in,
miserable to retrofit.

**Columnar historian storage — implemented (2026-07-09).** The per-signal
change-log is now a **typed column** (`times: VecDeque<u64>` + a native value
deque, kind fixed at first record) with a **boxed `(u64, Value)` column** for
`Enum`/`Bytes` signals — the D12 storage end-state
([`signal-trace.md`](signal-trace.md) §1). Scalars store ~12–16 B/sample vs the old
`(u64, Value)` pair's ~40 B, and the sweep's changed scalar leaves record through
**typed fast lanes** (`record_mirror_<t>_at`, fed by a native `read_cvar_scalar`
decode) that compare against the column tail natively — **no `Value` construction
on the hot record path**. This holds sweep memory + speed roughly flat as Phase-3
multiplies signal counts and capture lengths (fast-mode retention is unbounded).

**Known seam — `M×R` zero-latency route re-evaluation.** The settled step
([`state-route-tables.md`](state-route-tables.md) §3) re-resolves the full
zero-latency route DAG (in cached topological order) before *each* of the `M`
members, so a member always sees fully-resolved forward dataflow. That is `M×R`
pure copies per tick where `R` is the zero-latency route count. It is correct and
simple, and fine at current scale; the optimization (resolve once per tick and let
each member read its already-final inputs, or per-member incoming-route slices) is
deferred here — the topo order is already cached across ticks (rebuilt only when the
wiring is dirty), so only the copies remain.

## 7. Lever 6 — parallelism (free aggregate throughput)

Fast mode scales across **processes** (pytest-xdist): aggregate = per-sim speed ×
cores. Single-threaded-fiber sims are ideal — one core each, zero contention.

## 8. Seams to bake in from the start

1. **Single-threaded fiber execution engine** (Lever 2 §2) — hard to retrofit.
2. **Continuous-vs-discrete split + gating** (Lever 3 §3) — hard to retrofit.
3. **Zero-alloc hot loop + columnar historian** (Lever §6) — hard to retrofit.
4. **Pluggable change-detector** naive-scan ↔ dirty-page (§5) — seam now, impl later.
5. **Model-owned integrator** (§4) so it can be upgraded.

## 9. Target

With levers 1–2 in place and 3–5 designed-for: **10–50× realtime on a laptop** is
realistic. Without lever 1: ~1× or worse.

## 10. Couplings

- **D1** — execution engine *is* the fiber model.
- **D2** — the boundary crossing is a fiber swap, single-thread.
- **D8** — ISR dispatch is cooperative, in the firmware context.
- **D9** — firmware bursts are instantaneous in sim time ⇒ no mid-task
  preemption needed (Lever 1 is *sufficient* and faithful in sim-time).
- **D6** — integrator choice sets the tick count.
- **D12** — historian cost (§5).

## 11. Measured baseline — Tier 0 (2026-07-09)

Phase-isolated, from the SIL suite's performance report (`pcs_bldc_sil`,
`report_performance`), averaged over 1000 ticks after warm-up on the dev laptop.
Two build configurations, **1 ms sim tick**; ×realtime = 1000 µs ÷ (µs/tick).
~430 cvar leaves mirrored per tick.

| phase | debug Rust + -O0 DLL | release Rust + -O2 DLL |
|---|---:|---:|
| firmware `advance_tick` alone | 5.9 µs (169×) | 4.1 µs (242×) |
| full engine `step` (measured) | 496 µs (2.0×) | 49 µs (20×) |
| empty engine `step` (floor) | 0.06 µs  | 0.01 µs  |
| derived (full − firmware) | 490 µs  | 45 µs  |

**Findings.** (1) The old "~443 µs/advance" baseline was the *unoptimized* full
step; building the Rust framework `--release` and the firmware DLL at `-O2 -g`
takes the full step **496 → 49 µs (~10×)** and the suite to **~20× realtime** with
no hot-path work. (2) The firmware itself is cheap (~4 µs); the cost lives in
voyant's **whole-namespace mirror sweep** (the `derived` row), so Tier 1/2 should
target the historian scan (Lever 4 — gate on "firmware ran" + dirty-page tracking,
§5), not the firmware. (3) The engine's own per-step overhead is negligible
(floor ≈ 0). Reproduce with `tools/run_sil.sh` (release) and
`tools/run_sil.sh --debug`.

## 12. After Tier 1 + Tier 2 (2026-07-09)

Same suite / method, after the shadow-`memcmp` sweep (Tier 1) + dense-index State
Table (Tier 2). **1 ms sim tick**, ~429 cvar leaves, release Rust + -O2 DLL.

| phase | before (Tier 0) | after (Tier 1+2) |
|---|---:|---:|
| firmware `advance_tick` alone | 4.1 µs (244×) | ~4.2 µs (237×) |
| **full engine `step` (measured)**  | **54 µs (18×)** | **~9.3 µs (107×)** |
| firmware-member step (sweep+flush) | —  | ~7.6 µs (131×) |
| derived (full − firmware) | 50 µs  | ~5.2 µs |
| ↳ shadow sweep + flush | —  | ~3.3 µs |
| ↳ model + route + propagate | —  | ~1.8 µs |

**Result: the owner target (full step ≤10 µs, >100× realtime) is met** — full
step ~9.0–9.4 µs run-to-run (~107× realtime), a **~6× speedup** over Tier 0's
54 µs. The remaining ~5.2 µs of voyant work splits ~3.3 µs shadow sweep+flush
(whole-shadow `memcmp` + decode/record of the ~30-60 actually-changing ADC/counter
leaves) and ~1.8 µs model+route+propagate (the `M×R` zero-latency re-eval + the
model's per-tick record). Both are now well within the ~6 µs/tick budget; the
report gained two breakdown rows (`firmware-member step` and the two `of which`
lines) to keep this attribution live and cheap.

## 13. After columnar historian (2026-07-09)

Same suite / method, after replacing the per-sample `VecDeque<(u64, Value)>`
change-log with **per-signal typed columns + a boxed fallback** (§6) and routing
the sweep's changed scalar leaves through **typed record fast lanes**. **1 ms sim
tick**, ~429 cvar leaves, release Rust + -O2 DLL.

| phase | before (Tier 1+2) | after (columnar) |
|---|---:|---:|
| firmware `advance_tick` alone | ~4.2 µs  | ~4.1 µs  |
| **full engine `step` (measured)**  | **~9.0 µs** | **~8.9 µs** |
| firmware-member step (sweep+flush) | ~7.3 µs  | ~7.0 µs  |
| ↳ shadow sweep + flush | ~3.1 µs  | ~2.8 µs  |

**Result.** The full step holds at ~8.9 µs (~112× realtime) — the target stays
met. The honest, attributable win is in the **sweep+flush** row (~3.1 → ~2.8 µs,
run-to-run): the changed scalar leaves now compare natively against the typed
column tail and store 12–16 B/sample instead of ~40 B, so the per-record work
shrank. The bigger point is **memory + scaling**: per-sample footprint dropped
~2.5× (f64: 40 → 16 B) to ~3.3× (u32: 40 → 12 B), which is what keeps unbounded
fast-mode capture flat as Phase 3 multiplies signals and capture lengths. The one
public ripple (owner-accepted): `current_value`/`value_at` return `Option<Value>`
by value and `changes` materializes `Vec<(u64, Value)>` — columnar storage cannot
hand out a `&Value`.

## 14. Release DLL to -O3 + LTO (2026-07-09)

The release SIL flavor (`tools/run_sil.sh` default) moved from **`-O2 -g`** to
**`-O3 -flto -g`** for the firmware DLL. `-flto -ffat-lto-objects` is added at
compile and `-flto` at link via a `PCS_LTO` switch in `native.cmake` (fat objects
keep concrete machine-code symbols so the SHARED library's `--whole-archive` /
`--export-all-symbols` and the DWARF-read statics all survive LTO). The `-O0 -g`
dev/debug flavor and the ARM build are untouched; no `-ffast-math` (FP semantics
unchanged). Same suite / method, release Rust, **1 ms sim tick, 429 cvar leaves**
(leaf count unchanged from §13 — LTO did not perturb the DWARF or elide a static).

| phase | before (-O2, §13) | after (-O3 -flto) |
|---|---:|---:|
| firmware `advance_tick` alone | ~4.1 µs  | ~2.9 µs (run 2.6–3.2) |
| **full engine `step` (measured)**  | **~8.9 µs** | **~7.6 µs (7.5–7.9)** |
| firmware-member step (sweep+flush) | ~7.0 µs  | ~6.1 µs  |

**Result.** The gain is firmware-side, as expected: `advance_tick` **~4.1 → ~2.9 µs
(~30%)**, which flows through to the full step **~8.9 → ~7.6 µs (~117× → ~132×
realtime)**. The voyant-side rows (sweep+flush, model+route) are unchanged work and
move only with run-to-run variance; the derived Rust cost is untouched by the DLL
flags. Debug flavor stays `-O0 -g` (430 leaves), all sanity checks PASS.

**LTO is Windows-only (2026-07-10).** *(the fine-grid re-baseline is §15)* The `-flto` half of this flavor applies on
**Windows (MinGW/GNU) only** — the `native.cmake` `PCS_LTO` flags are gated behind
`CMAKE_HOST_WIN32`. On Linux the GNU `-flto` ELF `.so` links but emits an **empty
DWARF map** (gimli reads 0 DIEs → the SIL reader finds no anchor), and macOS `gcc`
is Apple clang (no `-ffat-lto-objects`/plugin), so both keep `-O3` without LTO.
The Linux LTO+DWARF investigation is deferred (`backlog.md`); these perf numbers
are the Windows release flavor.

## 15. Opt-in fine grid + gated mirror (2026-08-15)

The engine grid became a **per-world choice** (`Sil::options().grid_us(50)`), with the
1 ms default untouched, and the whole-namespace mirror sweep moved onto a **sim-time
cadence** instead of running on every dispatching step. This is the §3 "gate discrete
work" / §5 "gate the historian scan" lever, finally exercised by a grid fine enough to
need it: at 50 µs (the 20 kHz PWM period) a control interrupt is due on *every* step,
so without a gate every step would pay the whole-namespace sweep.

**The gate.** `FirmwareMember` sweeps when `now - last_sweep >= sweep_period_us`
(default 1000 µs, `set_sweep_period_us`, world-level via `SilOptions::sweep_period_us`)
or when its shadow is cold. Everything else stays per-step / per-dispatch: route
propagation, port I/O, duplex, models, and the **in-sync cvar flush** — an inbound
value still reaches firmware memory before the firmware runs, so the gate never delays
the plant→firmware direction. Because the shadow mirrors *memory*, a withheld sweep
**delays** a record and never drops one: whatever differs from the shadow is picked up
whenever the sweep next runs. `Engine::mirror_now()` forces a sweep for an assert.

Two properties follow from measuring the cadence in sim time rather than in steps:
on any grid at least as coarse as the cadence, *every* dispatching step still sweeps —
so the whole default-grid suite behaves exactly as before — and the historian's cvar
latency bound is stated in sim time, independent of the grid a scenario chose.

**Coarse grid — re-baseline** (same suite / method as §14; 1 ms grid, 564 cvar leaves,
release Rust + `-O3 -flto` DLL; three back-to-back runs of each build on one laptop).

| phase | before | after (gate) |
|---|---:|---:|
| firmware `advance_time` + systick  | 0.90–0.93 µs | 0.87–0.89 µs |
| **full engine step (measured)** | **7.83–7.93 µs** | **7.68–7.84 µs** |
| firmware-member step (sweep+flush) | 6.35–6.59 µs | 6.26–6.63 µs |

Unchanged within run-to-run noise, as the gate design requires: at a 1 ms grid the
1 ms cadence elapses between any two dispatching steps, so the sweep still runs on each.

**Fine grid — new baseline** (50 µs grid, same members and route as the coarse
full-step row: a model driving a firmware input cvar while the member mirrors 564
leaves; each world loads its own firmware copy; avg over 20 000 steps).

| phase | µs/step | ×realtime |
|---|---:|---:|
| full step, firmware's own 1 ms interrupts | 1.07–1.36 µs | 37–47× |
| + a 50 µs interrupt (every step dispatches)  | 2.12–2.32 µs | 22–24× |
| + a 50 µs interrupt, cadence off (`0`) | 3.01–3.03 µs | ~17× |

**Result: the target is met** — a 50 µs world runs at ~22–47× realtime, comfortably
past the ≥10× (≤5 µs/step) bar. The gate is worth ~0.9 µs on every step that dispatches
without needing a mirror: what it removes is the whole-shadow `memcmp` traffic on the
steps that fall between mirrors (the decode+record of *changed* leaves is proportional
to changes, not to steps, so it is paid once per cadence either way).

**Fast set (not built).** A later stage needs a handful of ISR-written sample statics
mirrored at grid resolution while the rest of the namespace stays cadenced. That slots
in as a second range group built alongside the existing one in `build_shadow` and swept
*ahead of* the gate in `out_sync_cvars`; the gate is one `if` in front of a whole-set
sweep, so it neither shares nor constrains that group.

## 16. Stage-7 perf pass, phase 2a (2026-08-30)

Board world on the 50 µs grid, release, bridge dark, member-isolation rows
from the perf binary's `-- board-world report --` section (new):

| change | µs/step | ×realtime |
|---|---:|---:|
| baseline (1 µs integrator, string-key IO)  | 25.0 | 2.0× |
| motor integrator sub-step 1 → 5 µs | 18.3 | 2.7× |
| `SigHandle` resolve-once port IO | 6.8 | 7.3× |

- The plant is not the floor it looked like at §15: ~85% of its cost was
  avoidable (per-access `SignalId` construction + hashing — ~450k/sim-s — and
  4/5 of the integrator iterations). Post-pass shares: firmware member 3.0
  (per-step Binding sync + fiber ISR), motor 2.4 (the ODE itself), encoders
  0.67, sense 0.38, engine residual ~0.3. **Read the shares as indicative
  only** — they come from the perf binary's world-with/world-without
  subtraction, which attributes member interactions to whichever member was
  disabled and can therefore report a negative share (`backlog.md`). The
  full-world totals in the tables are sound; the splits are not.
- Integrator 5 µs is owner-decided and measured-identical: all physics tests
  and the north-star residuals hold at it. It has real margin — the electrical
  time constant is L/R = 340 µs, so forward Euler is stable below 2·L/R =
  680 µs, 136× out. The accuracy limit is the explicitly-forced BEMF term, so
  error scales with ω_e·dt: 5 µs tracks a 1 µs reference to ~1–2 % across
  10 Hz–5 kHz electrical, and coarser steps do not — 10 µs drifts 30 % at
  2 kHz. The constant is not a free knob.
- Models resolve `SigHandle`s at enable (`StateTable::handle` /
  `current_f64` / `record_by` — the public face of the index lanes routes
  already used). Member-side write short-circuiting was measured moot after
  this (0.3–0.4 µs/model total).
- Next lever: member-declared cadence / event-driven advance —
  [`member-cadence.md`](member-cadence.md).

## 17. Stage-7 perf pass, phase 2b: member-declared cadence (2026-08-30)

[`member-cadence.md`](member-cadence.md) landed: `Cadence` on the `Member`
trait (`EveryStep` default), encoders `OnDemand` (bus-driven — `transfer`
samples the table at the transaction instant, no scheduled advance, no
propagation pass), sense `OnInputChange` (post-epsilon input-dirty bits fed
by route propagation + scenario writes), and the firmware member's per-step
port-cache fill gated on its input-dirty bit. Same board-world row:

| change | µs/step | ×realtime |
|---|---:|---:|
| phase 2a exit (§16) | 6.8 | 7.3× |
| member-declared cadence (phase 2b) | 5.7 | 8.8× |

- Post-pass shares (bridge dark): firmware member 2.64 (was 3.0 — the port
  fill gates off on quiet steps), motor 2.43 (unchanged — `EveryStep`, the
  real ODE), sense 0.23 (was 0.38), both encoders at measurement-noise level
  (was 0.67 combined; their two zero-latency propagation passes vanished with
  them).
- Measured-identical, as the design requires: north-star residuals exactly
  13.6 / 16.8 mA over 800 periods; full suites green in both cargo profiles.
- Cost now tracks events, not the grid: a spinning plant keeps sense + fw
  fill hot (currents change every step); idle worlds pay ~only motor + tick.
  The share split carries §16's caveat: the attribution instrument is
  subtraction-based and indicative only.
- Next lever: the engine-side next-event queue (skip empty grid steps
  outright) — `sim-interrupts.md` §5; cadence made "next event" well-defined.
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

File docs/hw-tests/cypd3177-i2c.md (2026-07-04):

# HW test plan & execution record — CYPD3177 / I2C milestone

Bench-validation plan and execution log for the `cypd3177-i2c` milestone
(see [`../milestones/cypd3177-i2c.md`](../milestones/cypd3177-i2c.md)). It
records the hardware tests that give confidence in specs SIL alone cannot cover
— the real I2C transaction against real silicon and the *true* negotiated PD
contract — and traces executed runs back to the specs via OpenFastTrace.

## How this works (trial convention)

SIL/unit tests remain the automated OFT `test` coverage that CI enforces. This
doc adds a *second*, hardware-grounded coverage source for the specs that
warrant it. Not every spec needs a HW test.

- **Planned case** — a heading, the spec it will cover written as plain prose
  (`Covers on execution: <spec-id>`), a procedure, and the expected result. It
  carries **no** OFT item ID, so it provides **no** coverage. A written-but-unrun
  test cannot fake traceability.
- **Executed case** — on a real bench run, the case is promoted: it gains an OFT
  item ID line `` `test~<topic>_hw_<NNN>~1` ``, a dated **Executions** log entry
  (result, board rev, conditions), and a real `Covers:` block. OFT then counts
  it as `test` coverage of the linked spec.

These `test~…` items live here, outside `specs/`, so `tools/validate-specs.py`
(which governs `sys`/`fw`/`app` requirement IDs) does not touch them — they are
test artifacts, like the `// [test->…]` tags in `.c` unit tests.

**Tracing with HW records included:**

```sh
tools/oft/oft.sh trace specs/ sw/lib sw/fw docs/hw-tests/
```

The path `docs/hw-tests/` must be added to the trace invocation for these
records to count. Until a case is executed and promoted, this doc contributes
nothing to the trace (planned cases are inert prose).

## Planned cases — `sys~pd_001~1` (USB-PD sink status monitoring)

These validate the spec's acceptance against physical ground truth. They become
runnable once `dev_CYPD3177` lands (milestone step 4) and are executed on the
bench before the milestone merges.

### HWT-PD-001 — Negotiated contract matches a known source
Covers on execution: `sys~pd_001~1`
Procedure: power the board from a USB-PD source of known capability (e.g. a
20 V / 3 A adapter or programmable USB-PD tester); read the exposed negotiated
voltage and current.
Expected: exposed negotiated voltage and current equal the contract actually
negotiated (consistent with the board's strapped VBUS_MIN/MAX and ISNK request).
Executions: none yet.

### HWT-PD-002 — Live VBUS matches meter
Covers on execution: `sys~pd_001~1`
Procedure: measure the VBUS rail with a calibrated multimeter (or scope) at the
same instant the exposed VBUS voltage is read.
Expected: exposed VBUS within ±0.1 V of the meter reading.
Executions: none yet.

### HWT-PD-003 — Type-C connection status matches physical attach
Covers on execution: `sys~pd_001~1`
Procedure: read the exposed Type-C connection status with the USB-C cable
attached, and again after detach/reattach.
Expected: exposed Type-C connection status matches the physical attach state.
Executions: none yet.

### HWT-PD-004 — Reachability reflects controller responsiveness
Covers on execution: `sys~pd_001~1`
Procedure: in normal operation, read the exposed reachability status; then induce
a non-responding condition on the HPI bus (bus-fault injection / scope-observed
NAK). Note: the CYPD3177 supplies the board rail, so a full power-loss case is
not exercised here.
Expected: reachability reports available when the controller responds and
unavailable when it does not.
Executions: none yet.

### HWT-PD-005 — Device-alive probe on real silicon
Covers on execution: `sys~pd_001~1`
Procedure: on real hardware, exercise the device-alive probe and capture the raw
DEVICE_MODE (`0x0000`) value; confirm the I2C transaction completes with the
peripheral's clock stretching enabled.
Expected: the probe reports the controller present; the raw DEVICE_MODE reads as
the real-silicon value (`0x95`, per the Infineon-confirmed erratum), closing the
milestone's verify-on-hardware flag.
Executions: none yet.

## Executed cases

(none yet — promoted here from the plan above as bench runs are performed.)

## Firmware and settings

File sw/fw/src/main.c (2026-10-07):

#include "lib_build.h"
#include "HW_systemClock.h"
#include "HW_GPIO.h"
#include "HW_OPAMP.h"
#include "HW_ADC.h"
#include "HW_SPI.h"
#include "HW_I2C.h"
#include "HW_TIM.h"
#include "HW_DMA.h"

// Task creation, the periodic tasks, and every io/dev/app module they drive are
// target-uniform: the SIL (native) build runs the SAME FreeRTOS tasks against
// the sim HW drivers that the embedded build runs against the STM32G4 drivers.
// Target divergence lives only at the hw-layer seam and in the small gated
// blocks below (HAL bring-up, the HAL timebase callback, printf retarget, and
// each target's entry path).
#include <stdio.h>
#include "FreeRTOS.h"
#include "task.h"
#include "lib_utils.h"
#include "lib_timer.h"
#include "HW_USB.h"
#include "IO_serial.h"
#include "IO_COBSFrame.h"
#include "IO_AS5048.h"
#include "IO_SK6805.h"
#include "IO_i2c.h"
#include "IO_bridge.h"
#include "dev_switch.h"
#include "dev_CYPD3177.h"
#include "dev_gateDriver.h"
#include "app_rgbLedRing.h"
#include "app_motorControl.h"
#include "app_userControls.h"
#include "app_server.h"

#if (BUILD_TARGET == BUILD_TARGET_STM32G4)
  #include "stm32g4xx_hal.h"  // HAL_Init
#endif

extern const HW_systemClock_config_S HW_systemClock_config;
extern const HW_GPIO_config_S HW_GPIO_config;
extern const HW_OPAMP_config_S HW_OPAMP_config;
extern const HW_ADC_config_S HW_ADC_config;
extern const HW_SPI_config_S HW_SPI_config;
extern const HW_I2C_config_S HW_I2C_config;
extern const HW_TIM_config_S HW_TIM_config;
extern const HW_DMA_config_S HW_DMA_config;
extern const IO_i2c_config_S IO_i2c_config;
extern const IO_bridge_config_S IO_bridge_config;

extern const IO_AS5048_config_S IO_AS5048_config;
extern const IO_SK6805_config_S IO_SK6805_config;
extern const dev_switch_config_S dev_switch_config;
extern const dev_CYPD3177_config_S dev_CYPD3177_config;
extern const dev_gateDriver_config_S dev_gateDriver_config;
extern const IO_serial_config_S IO_serial_config;
extern const IO_COBSFrame_config_S IO_COBSFrame_config;
extern const app_rgbLedRing_config_S app_rgbLedRing_config;
extern const app_motorControl_config_S app_motorControl_config;
extern const app_userControls_config_S app_userControls_config;

#if (BUILD_TARGET == BUILD_TARGET_STM32G4)
// stm32g4xx_it.c's TIM6_DAC_IRQHandler references hdac1; the DAC isn't
// integrated, so a zeroed weak handle lets it.o link (the DAC interrupt never
// fires). TODO: remove when a DAC driver lands.
__attribute__((weak)) DAC_HandleTypeDef hdac1;

// The HAL time base runs on TIM6 (stm32g4xx_hal_timebase_tim.c), leaving
// SysTick to FreeRTOS. TIM6_DAC_IRQHandler -> HAL_TIM_IRQHandler fires this
// callback each 1 ms; without it HAL_IncTick is never called, uwTick stays
// frozen at 0, and every HAL timeout (ADC/SPI/I2C PollForX) waits forever
// instead of bounding. CubeMX emits this in its main.c, which this project
// doesn't vendor, so it lives here.
void HAL_TIM_PeriodElapsedCallback(TIM_HandleTypeDef * htim)
{
    if (htim->Instance == TIM6)
    {
        HAL_IncTick();
    }
}
#endif


void Error_Handler(void)
{
    while (1)
    {
    }
}

// FreeRTOS static-allocation memory providers (configSUPPORT_STATIC_ALLOCATION=1).
// cmsis_os2.c normally supplies these; we provide them since we use the native
// FreeRTOS API without the CMSIS-RTOS wrapper. Target-uniform: the board config
// and the SIL fiber-port config both enable static allocation, and the kernel
// creates the idle task (and, where enabled, the timer task) through these on
// either target. The timer-task provider is only needed when software timers
// are compiled in (configUSE_TIMERS).
#if (configSUPPORT_STATIC_ALLOCATION == 1)
static StaticTask_t idleTaskTcb;
static StackType_t  idleTaskStack[configMINIMAL_STACK_SIZE];
void vApplicationGetIdleTaskMemory(StaticTask_t ** ppxTcb, StackType_t ** ppxStack, uint32_t * pulSize)
{
    *ppxTcb   = &idleTaskTcb;
    *ppxStack = idleTaskStack;
    *pulSize  = configMINIMAL_STACK_SIZE;
}

#if (configUSE_TIMERS == 1)
static StaticTask_t timerTaskTcb;
static StackType_t  timerTaskStack[configTIMER_TASK_STACK_DEPTH];
void vApplicationGetTimerTaskMemory(StaticTask_t ** ppxTcb, StackType_t ** ppxStack, uint32_t * pulSize)
{
    *ppxTcb   = &timerTaskTcb;
    *ppxStack = timerTaskStack;
    *pulSize  = configTIMER_TASK_STACK_DEPTH;
}
#endif
#endif

#define TASK_PRIORITY_1MS   (configMAX_PRIORITIES - 1U)
#define TASK_PRIORITY_10MS  (configMAX_PRIORITIES - 2U)
#define TASK_PRIORITY_USB   (configMAX_PRIORITIES - 3U)
#define TASK_PRIORITY_SERVER (configMAX_PRIORITIES - 4U)
#define TASK_PRIORITY_200MS (configMAX_PRIORITIES - 5U)

// --- Task profiling --------------------------------------------------------
// Per-task worst-case body duration in microseconds. task_usb blocks on its
// event queue, so it is not profiled.
typedef enum
{
    PROFILE_TASK_1MS,
    PROFILE_TASK_10MS,
    PROFILE_TASK_200MS,
    PROFILE_TASK_SERVER,
    PROFILE_TASK_COUNT,
} profileTask_E;

static volatile uint32_t profileMaxUs[PROFILE_TASK_COUNT];

#if (BUILD_TARGET == BUILD_TARGET_SIM)
// Sim-only trace window the SIL scenarios watch (app_server_config.c owns it).
extern uint32_t app_server_simTraceWindow32[];
#endif

// --- Bridge cycle probe (fw~mc_018) ----------------------------------------
// Microsecond maxima from cycle-callback entry to the end of the commutation
// step and to callback exit; the host clears either by writing zero to it.
// [impl->fw~mc_018~1]
static volatile uint32_t main_cycleProbe_stepMax_us;
static volatile uint32_t main_cycleProbe_callbackMax_us;

// --- Per-task heartbeat counters (SIL liveness) ----------------------------
// One free-running counter per task, bumped once per loop-body iteration.
// Unlike profileMaxUs (which resets every telemetry window), these are
// monotonic — the SIL driver reads them by DWARF path to prove each real task
// is actually advancing on the native scheduler, and they are candidate State
// Table signals. Target-uniform; volatile so the external (DLL/DWARF) view is
// never stale.
static volatile uint32_t task1msRuns;
static volatile uint32_t task10msRuns;
static volatile uint32_t task200msRuns;
static volatile uint32_t taskUsbRuns;
static volatile uint32_t serverRuns;

/* Private Function Declarations */

// Init helpers shared by both targets' entry paths; main.c stays the only
// caller of Error_Handler.
static bool main_private_hwInit(void);
static bool main_private_appInit(void);
static bool main_private_createTasks(void);
static void main_private_bridgeCycle(IO_bridge_channel_E channel, void * context);

// Fold one body execution's duration into the task's window max.
static void profileUpdate(profileTask_E task, uint32_t durationUs)
{
    if (durationUs > profileMaxUs[task])
    {
        profileMaxUs[task] = durationUs;
    }
}

static void task_1ms(void * params)
{
    (void)params;
    TickType_t lastWake = xTaskGetTickCount();
    for (;;)
    {
        vTaskDelayUntil(&lastWake, pdMS_TO_TICKS(1U));
        task1msRuns++;
        const uint32_t profileStartUs = (uint32_t)lib_timer_getTime_us();

        // hw
        HW_GPIO_run1ms();   // cache input-pin levels before anything reads them
        HW_ADC_run1ms();    // sample enabled ADC inputs (software-triggered, polled)

        // io
        IO_AS5048_run1ms();

        // dev
        dev_switch_run1ms();   // debounce switches off the cached GPIO snapshot

        // app
        app_userControls_run1ms();   // button + dial -> motor mode/velocity commands
        app_motorControl_run1ms();   // in-module overcurrent trip + enable gating (fw~safety_001 / fw~mc_006)
#if (BUILD_TARGET == BUILD_TARGET_SIM)
        // Sim trace window word [0]: the SIL trace scenarios' 1 kHz signal.
        app_server_simTraceWindow32[0]++;
#endif

        profileUpdate(PROFILE_TASK_1MS, (uint32_t)lib_timer_getTime_us() - profileStartUs);
    }
}

static void task_10ms(void * params)
{
    (void)params;
    TickType_t lastWake = xTaskGetTickCount();
    for (;;)
    {
        vTaskDelayUntil(&lastWake, pdMS_TO_TICKS(10U));
        task10msRuns++;
        const uint32_t profileStartUs = (uint32_t)lib_timer_getTime_us();

        // hw

        // io

        // dev

        // app
        app_rgbLedRing_run10ms();

        profileUpdate(PROFILE_TASK_10MS, (uint32_t)lib_timer_getTime_us() - profileStartUs);
    }
}

// Slow background sampling. Hosts blocking work (the PD-sink I2C poll), so it
// runs at the lowest priority — every real-time task preempts it.
static void task_200ms(void * params)
{
    (void)params;
    TickType_t lastWake = xTaskGetTickCount();
    for (;;)
    {
        vTaskDelayUntil(&lastWake, pdMS_TO_TICKS(200U));
        task200msRuns++;
        const uint32_t profileStartUs = (uint32_t)lib_timer_getTime_us();

        // hw

        // io

        // dev
        dev_CYPD3177_run200ms();
        dev_gateDriver_run200ms();

        // The gate driver holds nFAULT low until it is configured, so TIM1
        // latches a break flag every boot. Clear that stale latch once the
        // driver first reports operational; later latches are real faults.
        static bool bridgeBreakLatchCleared = false;
        if ((!bridgeBreakLatchCleared) &&
            (dev_gateDriver_isOperational(DEV_GATEDRIVER_CHANNEL_MAIN)))
        {
            bridgeBreakLatchCleared = IO_bridge_clearBreakFlags(IO_BRIDGE_CHANNEL_MOTOR);
        }

        // app

        // 1 Hz heartbeat through printf: exercises the log stream end to end
        // (fw~obs_log_001/002) and gives any bench session a liveness line.
        if ((task200msRuns % 5U) == 0U)
        {
            printf("heartbeat %lus up, server %lu runs\n",
                   (unsigned long)(task200msRuns / 5U),
                   (unsigned long)serverRuns);
        }

        profileUpdate(PROFILE_TASK_200MS, (uint32_t)lib_timer_getTime_us() - profileStartUs);
    }
}

// Dedicated USB device-service task. HW_USB_run() blocks on the TinyUSB event
// queue and wakes on the USB ISR, so the stack is serviced on demand rather than
// polled. Sits below the periodic tasks (they preempt it) so its variable,
// load-dependent work never adds jitter to their cadence.
static void task_usb(void * params)
{
    (void)params;
    for (;;)
    {
        taskUsbRuns++;
        HW_USB_run();
    }
}


// Protocol server: prioritized below the periodic control tasks, so serving
// the host never delays sampling or commutation.
static void task_server(void * params)
{
    (void)params;
    TickType_t lastWake = xTaskGetTickCount();
    for (;;)
    {
        // A pass that overran its tick is not made up: back-to-back passes
        // would each drain the few records that landed during the last one,
        // fragmenting the stream. The next pass waits a whole tick instead.
        // Strictly more than one tick: a pass that merely straddles a tick
        // boundary still wakes on schedule, or the task loses a pass in ten.
        const TickType_t now = xTaskGetTickCount();
        if ((TickType_t)(now - lastWake) > pdMS_TO_TICKS(1U))
        {
            lastWake = now;
        }
        vTaskDelayUntil(&lastWake, pdMS_TO_TICKS(1U));
        serverRuns++;
        const uint32_t profileStartUs = (uint32_t)lib_timer_getTime_us();

        app_server_run1ms();

        profileUpdate(PROFILE_TASK_SERVER, (uint32_t)lib_timer_getTime_us() - profileStartUs);
    }
}

#if (BUILD_TARGET == BUILD_TARGET_STM32G4)
// Retarget printf into the server's log capture (fw~obs_log_001): syscalls.c's
// weak _write calls __io_putchar. Native uses its own libc stdio, so this hook
// is embedded-only.
int __io_putchar(int ch)
{
    app_server_logByte((uint8_t) ch);
    return ch;
}
#endif

// The PWM-synchronous cycle, entered from the bridge's per-cycle callback in
// injected-completion ISR context: no FreeRTOS call, no lib_timer, no printf.
// [impl->fw~mc_018~1]
static void main_private_bridgeCycle(IO_bridge_channel_E channel, void * context)
{
    (void)context;
    uint32_t entry_us = 0U;
    (void)HW_TIM_getCounter(IO_bridge_config.channels[channel].timeBasePeripheral, &entry_us);

    // --- commutation step (fw~mc_015): the active method's step lands here ---
    // An empty step measures zero, and its own counter read arrives with it.
    main_cycleProbe_stepMax_us = 0U;

#if (BUILD_TARGET == BUILD_TARGET_SIM)
    // Sim trace window word [1]: the SIL trace scenarios' per-cycle signal,
    // word [2] its complement - a lockstep pair the coherence test checks.
    app_server_simTraceWindow32[1]++;
    app_server_simTraceWindow32[2] = ~app_server_simTraceWindow32[1];
#endif
    app_server_sampleCycle();   // capture trace watches after the step (fw~conn_trace_004)

    uint32_t exit_us = 0U;
    (void)HW_TIM_getCounter(IO_bridge_config.channels[channel].timeBasePeripheral, &exit_us);
    const uint32_t callbackDuration_us = exit_us - entry_us;
    if (callbackDuration_us > main_cycleProbe_callbackMax_us)
    {
        main_cycleProbe_callbackMax_us = callbackDuration_us;
    }
}

// HW-layer init, shared by both targets' entry paths.
static bool main_private_hwInit(void)
{
    bool ok = true;
    ok &= HW_systemClock_init(&HW_systemClock_config);
    ok &= HW_GPIO_init(&HW_GPIO_config);
    ok &= HW_OPAMP_init(&HW_OPAMP_config);   // before ADC: op-amps must be calibrated and running before the ADC samples their internal outputs
    ok &= HW_DMA_init(&HW_DMA_config);   // must run before SPI and ADC init()
    ok &= HW_ADC_init(&HW_ADC_config);
    ok &= HW_SPI_init(&HW_SPI_config);
    ok &= HW_I2C_init(&HW_I2C_config);
    ok &= HW_TIM_init(&HW_TIM_config);
    return ok;
}

// IO/dev/app-layer init, shared by both targets' entry paths. Aggregates each
// module's bool the same way main_private_hwInit does.
static bool main_private_appInit(void)
{
    bool ok = true;
    ok &= IO_AS5048_init(&IO_AS5048_config);
    ok &= IO_SK6805_init(&IO_SK6805_config);
    ok &= IO_i2c_init(&IO_i2c_config);
    ok &= IO_bridge_init(&IO_bridge_config);
    ok &= dev_switch_init(&dev_switch_config);
    ok &= dev_CYPD3177_init(&dev_CYPD3177_config);
    ok &= dev_gateDriver_init(&dev_gateDriver_config);
    ok &= app_rgbLedRing_init(&app_rgbLedRing_config);
    ok &= app_motorControl_init(&app_motorControl_config);
    ok &= app_userControls_init(&app_userControls_config);
    ok &= HW_USB_init();   // USB device stack (serviced in task_usb)
    ok &= IO_serial_init(&IO_serial_config);
    ok &= IO_COBSFrame_init(&IO_COBSFrame_config);
    ok &= app_server_init(&app_server_config);
    // Last: the callback's first firing must find every module it drives up.
    ok &= IO_bridge_registerCycleCallback(IO_BRIDGE_CHANNEL_MOTOR, main_private_bridgeCycle, NULL);
    return ok;
}

// Spawn the periodic tasks. Same names/priorities/stacks on both targets; each
// allocates from the FreeRTOS heap, so a failure here (e.g. heap exhaustion) is
// surfaced to the caller to halt loudly rather than silently drop a task.
static bool main_private_createTasks(void)
{
    bool ok = (xTaskCreate(task_1ms, "task_1ms", configMINIMAL_STACK_SIZE * 2U,
                           NULL, TASK_PRIORITY_1MS, NULL) == pdPASS);
    ok &= (xTaskCreate(task_10ms, "task_10ms", configMINIMAL_STACK_SIZE * 2U,
                       NULL, TASK_PRIORITY_10MS, NULL) == pdPASS);
    ok &= (xTaskCreate(task_usb, "usbd", configMINIMAL_STACK_SIZE * 2U,
                       NULL, TASK_PRIORITY_USB, NULL) == pdPASS);
    ok &= (xTaskCreate(task_server, "server", 512U,
                       NULL, TASK_PRIORITY_SERVER, NULL) == pdPASS);
    ok &= (xTaskCreate(task_200ms, "task_200ms", configMINIMAL_STACK_SIZE * 2U,
                       NULL, TASK_PRIORITY_200MS, NULL) == pdPASS);
    return ok;
}

#if (BUILD_TARGET == BUILD_TARGET_SIM)
#include "sil_fw.h"

// Native fiber-port primitives (provided by the cooperative fiber port).
extern void vPortYieldToScheduler(void);
extern BaseType_t xSilDispatchIsr(void (*pxHandler)(void));

// Quiescence handoff: when every task is blocked the idle task runs and hands
// control back to the driver (framework) fiber.
void vApplicationIdleHook(void)
{
    vPortYieldToScheduler();
}

// --- SIL control ABI (sil_fw.h) --------------------------------------------
// The framework drives these; pacing (fast vs realtime) is the driver's choice.
// The bring-up path is identical to the embedded main() below (minus HAL_Init):
// the SAME HW/app init and the SAME four tasks. The fiber port runs the
// scheduler to first quiescence and returns.

void sil_fw_setHooks(const SIL_ports_hooks_S * const hooks)
{
    SIL_ports_setHooks(hooks);
}

void sil_fw_setIrqHooks(const SIL_irq_hooks_S * const hooks)
{
    SIL_irq_setHooks(hooks);
}

bool sil_fw_start(void)
{
    bool ok = main_private_hwInit();
    ok = ok && main_private_appInit();
    ok = ok && main_private_createTasks();
    if (ok)
    {
        // Fiber port: runs to first quiescence (all tasks blocked) and returns.
        vTaskStartScheduler();
    }
    return ok;
}

void sil_fw_advance_time(uint32_t elapsed_us)
{
    // Called every engine step BEFORE any interrupt is dispatched, so a handler
    // (the kernel tick included) reads the timebase of the step it runs in.
    HW_TIM_advanceTime(elapsed_us);
}

bool sil_fw_dispatch_isr(SIL_irq_handler_F handler)
{
    return (xSilDispatchIsr(handler) != pdFALSE);
}

void sil_fw_shutdown(void)
{
    vPortEndScheduler();
}
#endif

#if (BUILD_TARGET == BUILD_TARGET_STM32G4)
int main(void)
{
    // TODO: channelize HAL_Init into an HW_halCore module so main.c doesn't
    // need a target-specific include. For now, gate it.
    HAL_Init();

    bool initSuccess = main_private_hwInit();
    initSuccess &= main_private_appInit();
    if (!initSuccess)
    {
        Error_Handler();
    }

    // Spawn the periodic tasks and hand control to the scheduler.
    // vTaskStartScheduler() does not return.
    if (!main_private_createTasks())
    {
        Error_Handler();
    }

    vTaskStartScheduler();
    return 0;
}
#endif

#if (BUILD_TARGET == BUILD_TARGET_SIM)
// Standalone boot smoke check over the control ABI (sil_fw.h). Unused inside the
// DLL — the Rust framework is the driver. It boots and tears down, nothing more:
// with no framework hooks installed nothing registers an interrupt, so no kernel
// tick fires and the firmware cannot advance (docs/sil/sim-interrupts.md).
int main(void)
{
    if (!sil_fw_start())
    {
        return 1;
    }
    sil_fw_shutdown();
    return 0;
}
#endif

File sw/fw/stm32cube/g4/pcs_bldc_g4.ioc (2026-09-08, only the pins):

Mcu.UserName=STM32G431VBTx
PA0.Signal=ADC1_IN1
PA1.Signal=OPAMP3_VINP
PA10.Signal=USART1_RX
PA11.Signal=USB_DM
PA12.Signal=USB_DP
PA13.Signal=SYS_JTMS-SWDIO
PA14.Signal=SYS_JTCK-SWCLK
PA2.Signal=USART2_TX
PA3.Signal=OPAMP1_VINP
PA4.Signal=COMP_DAC11_group
PA5.Signal=SPI1_SCK
PA6.Signal=SPI1_MISO
PA7.Signal=SPI1_MOSI
PA9.Signal=USART1_TX
PB0.Signal=OPAMP2_VINP
PB1.Signal=ADC1_IN12
PB10.Signal=GPIO_Input
PB2.Signal=GPIO_Output
PB3.Signal=SYS_JTDO-SWO
PB4.Signal=USART2_RX
PB5.Signal=SPI3_MOSI
PB6.Signal=GPXTI6
PB7.Signal=I2C1_SDA
PB8-BOOT0.Signal=I2C1_SCL
PC0.Signal=ADC1_IN6
PC1.Signal=ADC2_IN7
PC10.Signal=SPI3_SCK
PC13.Signal=GPXTI13
PC14-OSC32_IN.Signal=GPIO_Input
PC15-OSC32_OUT.Signal=GPIO_Input
PC2.Signal=ADC1_IN8
PC3.Signal=ADC2_IN9
PC4.Signal=GPIO_Output
PC5.Signal=ADC2_IN11
PC8.Signal=I2C3_SCL
PC9.Signal=I2C3_SDA
PE10.Signal=TIM1_CH2N
PE11.Signal=S_TIM1_CH2
PE12.Signal=TIM1_CH3N
PE13.Signal=S_TIM1_CH3
PE14.Signal=GPIO_Input
PE15.Signal=TIM1_BKIN
PE7.Signal=GPIO_Output
PE8.Signal=TIM1_CH1N
PE9.Signal=S_TIM1_CH1
PF0-OSC_IN.Signal=RCC_OSC_IN
PF1-OSC_OUT.Signal=RCC_OSC_OUT

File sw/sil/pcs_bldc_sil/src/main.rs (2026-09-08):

//! pcs_bldc SIL performance bin.
//!
//! Boots this board's firmware once and prints the phase-isolated per-tick
//! performance report. The behavioral checks live in `tests/` (run via
//! `cargo test` — see the crate lib docs); this bin is just the perf instrument,
//! plus an optional white-box per-tick scheduling table under `PCS_SIL_DIAG=1`.
//!
//! Usage: `cargo run -p pcs_bldc_sil -- [path-to-firmware-shared-lib]`
//!
//! Env vars:
//! - `PCS_SIL_DLL` / argv[1] — the firmware library (else the build-tree default).
//! - `PCS_SIL_DLL_FLAVOR` — label printed in the performance report.
//! - `PCS_SIL_DIAG=1` — after boot, print a white-box per-tick scheduling table
//!   (FreeRTOS `xTickCount`, `xNextTaskUnblockTime`, and the per-task heartbeat
//!   counters, all read by DWARF straight from firmware memory).

use pcs_bldc_sil::{dll_path, CountsRampModel, Sil, SOURCE, TICK_US};
use std::path::PathBuf;
use std::process::ExitCode;
use std::rc::Rc;
use std::time::Instant;
use voyant::{
    vsig_id, Engine, Firmware, FirmwareMember, Member, SignalId, StateTable,
    DEFAULT_SWEEP_PERIOD_US,
};

fn main() -> ExitCode {
    let path = std::env::args()
        .nth(1)
        .map(PathBuf::from)
        .unwrap_or_else(dll_path);

    println!("=== pcs_bldc SIL performance report ===");
    println!("loading firmware: {}", path.display());
    let fw = match Firmware::load(&path) {
        Ok(f) => Rc::new(f),
        Err(e) => {
            eprintln!("FATAL: failed to load firmware library: {e}");
            return ExitCode::FAILURE;
        }
    };
    if !fw.start() {
        eprintln!("FATAL: sil_fw_start() returned false");
        return ExitCode::FAILURE;
    }

    // Optional white-box diagnostic (PCS_SIL_DIAG=1); print-only, advances the handle.
    diag_per_tick_table(&fw);

    report_performance(&fw);
    report_fine_grid();
    report_board_world();

    fw.shutdown();
    ExitCode::SUCCESS
}

/// The FreeRTOS port's kernel-tick handler, which it registers with the interrupt
/// table at scheduler start. Driving a raw firmware step outside the engine means
/// advancing the timebase and dispatching this entry by hand.
const SYSTICK_ISR: &str = "vSilSysTickHandler";

/// White-box per-tick scheduling table, gated by `PCS_SIL_DIAG=1` (no-op otherwise):
/// advance the firmware one raw tick at a time and DWARF-read the FreeRTOS kernel's own
/// view alongside the per-task heartbeats. The resolved-address list surfaces DWARF
/// faults directly — two statics on one address means their reads alias.
fn diag_per_tick_table(fw: &Firmware) {
    if std::env::var("PCS_SIL_DIAG").ok().as_deref() != Some("1") {
        return;
    }
    const TICKS: u32 = 15;
    let systick = fw
        .resolve_func(SYSTICK_ISR)
        .expect("the fiber port's kernel-tick handler resolves by name");

    // Silence the default panic hook for the duration: a missing DWARF symbol makes
    // `read_cvar` panic, which we catch below and render as "n/a".
    let prev_hook = std::panic::take_hook();
    std::panic::set_hook(Box::new(|_| {}));
    let rd = |path: &str| -> String {
        std::panic::catch_unwind(std::panic::AssertUnwindSafe(|| fw.read_cvar(path)))
            .ok()
            .and_then(|v| v.as_u64())
            .map(|n| n.to_string())
            .unwrap_or_else(|| "n/a".into())
    };

    println!("\n-- DIAG: per-tick firmware scheduling table (PCS_SIL_DIAG=1) --");
    println!(
        "         DLL flavor: {}",
        std::env::var("PCS_SIL_DLL_FLAVOR").unwrap_or_else(|_| "unknown".into())
    );

    // Resolved runtime addresses of the statics the table reads. If two distinct
    // statics collapse to one address here, their reads alias — a per-variable
    // DWARF-resolution fault (e.g. same-TU file-scope `static`s on Mach-O).
    println!("         resolved addresses (watch for collisions):");
    for p in [
        "xTickCount",
        "task1msRuns",
        "task10msRuns",
        "serverRuns",
        "task200msRuns",
        "taskUsbRuns",
    ] {
        let a = fw
            .resolve_addr(p)
            .map(|a| format!("{a:#018x}"))
            .unwrap_or_else(|| "n/a".into());
        println!("           {p:<16} {a}");
    }

    println!(
        "         {:>4}  {:>10}  {:>9}  {:>7}  {:>8}  {:>5}  {:>7}",
        "tick", "xTickCount", "nextUnblk", "task1ms", "task10ms", "server", "taskUsb"
    );
    // Row 0 = post-boot baseline (all tasks just blocked; no tick applied yet).
    for i in 0..=TICKS {
        println!(
            "         {:>4}  {:>10}  {:>9}  {:>7}  {:>8}  {:>5}  {:>7}",
            i,
            rd("xTickCount"),
            rd("xNextTaskUnblockTime"),
            rd("task1msRuns"),
            rd("task10msRuns"),
            rd("serverRuns"),
            rd("taskUsbRuns")
        );
        if i < TICKS {
            fw.advance_time(TICK_US);
            fw.dispatch_isr(systick);
        }
    }

    std::panic::set_hook(prev_hook);
}
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

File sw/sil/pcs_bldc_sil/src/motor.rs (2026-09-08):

//! BLDC motor + averaged-duty inverter — the plant that closes the commutation loop.
//!
//! All ports live in the model's own namespace; the sim wiring routes the board's
//! bridge signals into them. Inputs: `vsig:<name>:{duty,enable}_{u,v,w}`, `moe`,
//! `v_bus` — per-leg normalized duty in [0,1], 0/1 enables, master output enable, bus
//! voltage. Outputs: `angle`, `velocity`, `phase_current_*`, `bus_current`, `torque`,
//! `terminal_voltage_*`, `bemf_*`, `neutral_voltage`.
//!
//! Each leg runs a hybrid mode machine — driven (duty × v_bus), diode-clamped to a
//! rail, or open — over a sinusoidal-BEMF (PMSM) R/L electrical model about a
//! floating neutral, plus J/B/Coulomb mechanics with a stick state at zero speed,
//! integrated semi-implicitly at
//! [`MOTOR_INTEGRATOR_STEP_PERIOD_US`] sub-steps. A disabled leg freewheels through
//! its body diode to exact zero then floats; a floating terminal re-clamps if it
//! leaves the rail window.

use std::f64::consts::{PI, TAU};

use crate::{observe_port, register_port};
use voyant::{vsig_id, Member, MemberCtx, SigHandle, SignalId, StateTable, Value};

pub const MOTOR_INTEGRATOR_STEP_PERIOD_US: u16 = 5;

const DIODE_ENGAGE_MARGIN_V: f64 = 0.005;

/// STSPIN32G4 target motor pole-pair count.
pub const DEFAULT_POLE_PAIRS: u8 = 14;

/// Electrical + mechanical motor parameters. Defaults are the bench-measured
/// iPower GM6208-150T values (`tools/trace_analysis/*`); `l_h` is a class-typical
/// estimate (its time constant sits below the capture bandwidth).
#[derive(Clone, Copy, Debug)]
pub struct MotorParams {
    /// Per-phase winding resistance (Ω).
    pub r_ohm: f64,
    /// Per-phase winding inductance (H).
    pub l_h: f64,
    /// Back-EMF constant (V per rad/s, mechanical).
    pub ke_v_per_mech_rad_s: f64,

    /// Rotor pole pairs (electrical revs per mechanical rev).
    pub pole_pairs: u8,
    /// Rotor + load inertia (kg·m²).
    pub j_kg_m2: f64,
    /// Viscous friction (Nm per rad/s).
    pub b_nm_per_rad_s: f64,
    /// Coulomb friction torque (Nm); breakaway equals it — the stick state holds
    /// the rotor until the drive torque exceeds it.
    pub t_c_nm: f64,
    /// Forward voltage drop over the body diodes of the bridge FETs
    pub v_d: f64,
}

impl Default for MotorParams {
    fn default() -> Self {
        Self {
            r_ohm: 14.7,
            l_h: 5.0e-3,
            ke_v_per_mech_rad_s: 0.55,
            pole_pairs: DEFAULT_POLE_PAIRS,
            j_kg_m2: 3.0e-4,
            b_nm_per_rad_s: 7.2e-4,
            t_c_nm: 4.4e-3,
            v_d: 0.8,
        }
    }
}

#[derive(Clone, Copy, PartialEq)]
pub enum Rail {
    Low,
    High,
}

#[derive(Clone, Copy, PartialEq)]
pub enum LegMode {
    Driven,
    Clamped(Rail),
    Open,
}

/// A sinusoidal-BEMF PM motor driven by an averaged-duty inverter. Reads the bridge
/// command + bus voltage from its input ports each tick and records the plant state on
/// its output ports (see the module doc for the port list).
pub struct MotorModel {
    name: String,
    params: MotorParams,

    // Integrated plant state.
    angle_rad: f64,
    velocity_rad_s: f64,
    phase_current_a: [f64; 3],
    torque_nm: f64,

    modes: [LegMode; 3],

    ports: MotorPorts,
}

/// Pre-resolved port handles (resolve-once; [`StateTable::handle`]), filled at
/// enable. `None` until then — a dark read stays 0.0, a write no-ops.
#[derive(Default, Clone, Copy)]
struct MotorPorts {
    v_bus: Option<SigHandle>,
    duty: [Option<SigHandle>; 3],
    enable: [Option<SigHandle>; 3],
    moe: Option<SigHandle>,

    angle: Option<SigHandle>,
    velocity: Option<SigHandle>,
    torque: Option<SigHandle>,
    phase_current: [Option<SigHandle>; 3],
    terminal_voltage: [Option<SigHandle>; 3],
    bemf: [Option<SigHandle>; 3],
    bus_current: Option<SigHandle>,
    neutral_voltage: Option<SigHandle>,
}

const N_PHASES: usize = 3;

fn bemf_shape(theta_e: f64) -> f64 {
    debug_assert!(theta_e.is_finite());

    // Sinusoidal machine (bench-measured, 4.1% rms vs pure sine —
    // tools/trace_analysis/bemf_spin).
    let t = theta_e.rem_euclid(TAU);
    t.sin()
}

impl MotorModel {
    /// A motor named `name`, its shaft at `initial_angle_rad`, with placeholder
    /// [`MotorParams`].
    pub fn new(name: &str, initial_angle_rad: f64) -> Self {
        Self {
            name: name.to_string(),
            params: MotorParams::default(),
            angle_rad: initial_angle_rad,
            velocity_rad_s: 0.0,
            phase_current_a: [0.0; 3],
            torque_nm: 0.0,
            modes: [LegMode::Open; 3],
            ports: MotorPorts::default(),
        }
    }

    /// Override the placeholder parameters.
    pub fn with_params(mut self, params: MotorParams) -> Self {
        self.params = params;
        self
    }

    fn port_id(&self, local: &str) -> SignalId {
        vsig_id(&self.name, local).expect("valid vsig id")
    }

    /// Record one output by handle.
    fn emit(st: &mut StateTable, h: Option<SigHandle>, x: f64) {
        if let Some(h) = h {
            let _ = st.record_by(h, Value::F64(x));
        }
    }
}
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

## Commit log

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2026-06-15 Fix ISR linking so interrupt handlers run; M0 bring-up scaffolding
    stm32g4xx_it.c lives in the static fw_hw lib, but the linker never pulled
    it.o — startup.s's weak Default_Handler aliases already satisfied the handler
    symbols — so SysTick/USB_LP/EXTI all fell through to the infinite-loop default.
    Link fw_hw with --whole-archive so the real handlers win. This froze uwTick,
    which broke HAL_Delay AND every HAL_GetTick-timeout init (HAL_ADC_Init).
    - arm-none-eabi: add -g3 for source-level live debugging (flash-only, no RAM cost).
    - main.c: weak hpcd_USB_FS stub so it.o links before the USB stack lands;
    temporary 1 Hz PC4 heartbeat smoke test (delete once USB serial is up).
    - gitignore .v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
    [main.c]
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2026-06-16 Bring up USB CDC over TinyUSB (M1) — serial print working on hardware
    - Vendor TinyUSB 0.20.0 (device + CDC + stm32_fsdev + FreeRTOS osal) at
    sw/lib/c/tinyusb; native API, cmsis_os2 wrapper excluded. tusb_config.h +
    pcs_tinyusb_config glue.
    - New sw/fw/src/io/usb module: USB clock routing (PLL-Q 48 MHz) + NVIC, a
    tud_task FreeRTOS task, CDC descriptors, printf->CDC retarget (unbuffered).
    - it.c handlers: USB_LP -> dcd_int_handler; USBWakeUp -> clear EXTI18. The
    unhandled USBWakeUp vector was falling into the infinite-loop
    Default_Handler, starving SysTick (frozen tick + failed enumeration).
    - Link: --start-group io_usb tinyusb (cyclic dep); --whole-archive hw_stm32g4
    (newlib sy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
    [main.c, pcs_bldc_g4.ioc]
2026-06-16 Read AS5048 encoder over SPI; print angle over USB CDC (M2)
    - Fix SPI BUS_1 for the AS5048: 8-bit frames, mode 1, /32 (4.5 MHz), and
    correct both encoder CS pins (PC4, PB2) to match the schematic. SPI1
    params now set in the .ioc so they survive regen; PB2 added as CS1 output.
    - Add channelized IO_AS5048 driver (shared/io + project channels), sampled
    by a new 1 ms FreeRTOS task; USB task prints motor + dial angle.
    - Bump FreeRTOS heap to 8 KB (now an .ioc parameter) and check xTaskCreate
    returns via Error_Handler — the silent heap-exhausted task-create was
    killing USB enumeration.
    [IO_AS5048_channels.c, main.c, pcs_bldc_g4.ioc]
2026-06-16 Drive SK6805 RGB LED ring over SPI (M3)
    - Add IO_SK6805 driver (shared io/ + project config seam): framebuffer
    expanded to 6 SPI bits per LED bit on BUS_3 (4.5 MHz), blocking transmit;
    invert flag for the board's inverting level shifter.
    - Reconfigure SPI BUS_3 to 8-bit / div32 / SW (blocking, no DMA).
    - main.c: LED bring-up task (a walking pixel) with a vTaskSuspendAll guard
    so the timed stream isn't chopped mid-transfer.
    - Centralize task priorities (encoder > LED > USB); USB_init takes its task
    priority so the LED cadence isn't starved by USB load.
    [main.c]
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2026-06-16 Add encoder reverse option + button-cycled LED modes
    - IO_AS5048: per-channel `reverse` flag (out = 360 - angle) to match an
    encoder mounted opposite the desired sense; enabled for both channels.
    - main.c: poll GPIO + debounce the user button in the 1 ms task; the LED task
    cycles modes on each button press — walk (dial sets a signed, reversible
    speed; wide pip), HSV colour picker (motor=hue, dial=saturation, both via
    bounded movement accumulators), dual encoder pips, off. The picked colour
    feeds the walk pip. Throwaway scaffolding pending a dedicated LED app.
    [IO_AS5048_channels.c, main.c]
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2026-06-19 Spec, test, and harden the HW_ADC driver (foundation sprint pilot)
    - specs/firmware/hal/adc.md: 8 specs for the ideal driver; 003 (mode
    taxonomy) and 008 (async completion) left OFT-uncovered as the to-do tracker.
    - Enforce contiguous regular ranks; add a pollable per-channel conversion
    status (HW_ADC_getStatus) set on poll timeout. run1ms stays void.
    - Fix rank handling: ADC_REGULAR/INJECTED_RANK_n are register-field
    encodings, not ordinals -- map via lookup tables (was mis-storing regular
    counts and reading JDR1 for every injected slot).
    - Sim: fault injection (HW_ADC_sim_setConversionStall) + Unity tests.
    - Drive HW_ADC_run1ms from the 1 ms task.
    [main.c]
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2026-06-20 Spec and channelize the SK6805 RGB LED driver (dual-target, tested)
    - specs/firmware/obs/rgb_leds.md: fw~obs_led_001..005 (init/validation,
    channel addressing, per-pixel framebuffer, transmit, invert polarity) under
    a new obs_led subtopic; covers sys~arch_001. Firmware README updated.
    - Channelize IO_SK6805: channel enum + per-channel config array, channel arg
    on setPixel/setAll/clear/update, per-channel framebuffer, AS5048-style init
    validation. Rename the project seam _config -> _channels.
    - Build io_SK6805 for native (un-gate; usb stays embedded-only) and add a
    Unity suite with a mock HW_SPI that decodes the emitted frame.
    - Update main.c's ledTask to the channelized API.
    - All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
    [main.c]
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2026-06-22 Add channelized app_rgbLedRing UI module + spec it (M2)
    - Spec the LED-ring UI as fw~obs_ring_001..003 (control loop / per-mode
    rendering / colour persistence), parent sys~arch_001, back-filling the
    throwaway ledTask demo behaviour.
    - Extract ledTask + helpers from main.c into a new app/ layer module
    (sw/lib/c/shared/app/rgbLedRing). Channelized: one instance per ring,
    all board wiring in the project app_rgbLedRing_channels seam, so no
    project channel names leak into lib code.
    - Native Unity suite compiles the module against a FreeRTOS + IO/dev mock
    harness; [impl->]/[test->] tags cover all three specs.
    - main.c now calls app_rgbLedRing_init(&app_rgbLedRing_config, TASK_PRIO_LED)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
    [main.c]
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2026-07-02 Implement HW_DMA dual-target driver (M3; covers fw~hal_dma_001..003)
    Generic single-shot memory<->peripheral DMA transfer engine, channelized
    like the other hw modules.
    - sim: full loopback model with tick-driven completion + SIL hooks
    (inject/inspect/force-error); 12-case Unity suite covering init
    validation, both transfer directions, busy/complete/error status, and
    exactly-once callback. Makes all three specs OFT-covered.
    - stm32g4: HAL_DMA-backed impl (HAL_DMA_Init + registered cplt/error
    callbacks; HAL_DMA_Start_IT; getStatus/registerCallback; irqHandler
    entry). Builds/links for ARM.
    - project channel config: SK6805_TX (mem->SPI3) + AS5048_RX (SPI1->mem).
    NVIC enable, board D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
    [HW_DMA_channels.c]
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2026-07-02 DMA-back the SK6805 LED transmit (M4, SK6805 TX half)
    Route the ~1.25 ms LED frame off the CPU via HW_DMA so it no longer
    blocks or needs a scheduler guard.
    - HW_SPI stm32g4: implement the DMA transfer mode for TX — kick the bus's
    TX DMA channel (HW_DMA_startTransfer), completion runs off the DMA IRQ
    (FIFO drain, CS deassert, status, callback). busConfig gains txDmaChannel;
    HW_SPI_init registers the completion callback with HW_DMA. RX/full-duplex
    DMA (encoder) still pending.
    - HW_DMA_init: arm each channel's NVIC line (the it.c handlers forward to
    HW_DMA_irqHandler).
    - main.c: init HW_DMA before HW_SPI.
    - SPI3 (SK6805 bus) -> DMA transfer mode, txDmaChannel = SK6805_TX.
    - app_rg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
    [main.c]
2026-07-02 Add per-task duration profiling to the telemetry stream
    Time each periodic task's body against the lib_timer microsecond base and
    track the worst-case (max) duration per task. telemetryTask emits the three
    maxes (task1ms_us / task10ms_us / telem_us) each window and resets them
    (snapshot-and-clear under a critical section so no sample is dropped).
    task1ms/task10ms are pure CPU time (their bodies never block); telem is
    wall-clock so it includes CDC backpressure waits. task_usb is event-driven
    (blocks on the USB queue) and is not profiled.
    [main.c]
2026-07-02 Batch telemetry into one CDC write per window
    Format each window's Teleplot packets into a single buffer and push them
    with one IO_serial_write, so the CDC FIFO is flushed once per window instead
    of once per byte (the printf -> __io_putchar path flushed after every char).
    Bench: telem_us dropped from ~16-20 ms to ~3.3 ms and the byte-drop
    corruption / plot jitter cleared.
    [main.c]
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2026-07-04 Wire up all board ADC channels; engineering-unit telemetry
    - 7 regular inputs across ADC1/ADC2 (phase + VBUS I/V sense, 5V/3V3
    rails), 47.5-cycle sampling; converter script now carries sConfig to
    every rank, not just the first
    - Force AUTDLY in polled mode: back-to-back rank EOCs coalesced and
    wedged the per-rank poll loop (first multi-rank config exposed it)
    - Restore HAL tick (TIM6 period-elapsed -> HAL_IncTick); every HAL
    timeout was silently dead
    - Telemetry: named signals scaled to A/V, signed fixed-point
    formatting; TX buffers 512 -> 1024
    [main.c, pcs_bldc_g4.ioc]
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2026-07-04 DWARF: read non-exported statics from Rust by var.member path
    sil-sys gains a DwarfMap (object + gimli) that parses the firmware DLL's
    .debug_info and resolves a var.member path to its link address + leaf size:
    top-level/static variables (DW_OP_addr), struct/union member offsets, and
    typedef/const/volatile pass-through to the underlying struct/base type.
    Firmware::load now parses DWARF and computes the ASLR slide from the
    sim_task1msRuns anchor (export-table runtime address vs DWARF link address);
    read_path_u32 resolves a path and reads the live in-process address.
    Proven: Rust reads HW_ADC_data.tickCounter -- a non-exported static struct
    member GetProcAddress can't reach -- climbing 1..20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
    [lib.rs, main.rs]
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2026-07-04 Finish DWARF: arrays, scalar types, typed read+write (Phase-2 exit met)
    DwarfMap now resolves arr[i] / nested paths and base/enum scalar kinds
    (signed/unsigned/float/bool); Firmware gains typed Value read/write
    (read_path_u32 replaced by read/write). sil-core reads the real ADC ramp
    HW_ADC_data.channelData[0].counts[6] (array element in a non-exported static)
    and writes HW_ADC_data.tickCounter, after which the firmware's HW_ADC_run1ms
    recomputes the ramp from the injected value (counts[6] = 96 + 1001 = 1097).
    Closes the Phase-2 exit: Rust steps the firmware, reads the ADC ramp by symbol,
    writes a global, and the firmware reacts.
    [lib.rs, main.rs]
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2026-07-04 State Table core: trait-backed signals addressed by canonical name
    Modularize voyant (value / dwarf / backend / state) and add the State Table:
    - value: the common Value enum + Scalar + scalar mem read/write helpers
    - backend: Firmware gains resolve_addr (path -> live ptr + kind) for cvar
    - state: Signal trait (read/write Value via &self), the cvar backing (firmware
    static reached by a DWARF-resolved live ptr), the SignalKey parser for
    <sig_type>:<source>:<local>[:<modifier>], and the StateTable registry
    (register + get/set by canonical name)
    pcs_bldc_sil drives firmware state through the table by name
    (cvar:pcs_bldc:HW_ADC_data...): reads the ADC ramp and injects tickCounter, the
    fir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
    [backend.rs, lib.rs, main.rs]
2026-07-04 State Table: pure-data historian (SignalId + change-log + resolver)
    Adopt the drafted signal.rs/state_table.rs design and reconcile the crate:
    - signal: SignalId (owned, validated sig_type:source:name[:modifier]) + the
    logical Value (F32/F64/I32/U32/U64/Bool/Enum/Bytes) + approx_eq
    - state_table: pure-data registry + per-signal change-logged history + current
    cache + injection overrides + per-signal epsilon (default 1e-3) + time-based
    retention (None = unbounded). record/force_record/current_value(O(1))/
    value_at(O(log n) ZOH). No FFI in the data structure.
    - backend: the cvar sample-resolver (read_cvar/write_cvar) coerces firmware
    scalar widths <-> Value; the only unsafe/DWARF par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
    [backend.rs, lib.rs, main.rs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]
2026-07-04 DWARF: resolve enum cvars to their symbolic name (Value::Enum)
    Parse DW_TAG_enumeration_type + DW_TAG_enumerator children into a value->name
    map; resolve() now returns a Leaf (Scalar | Enum(type_off)) so the cvar
    resolver distinguishes an enum field from a plain int. read_cvar yields
    Value::Enum(name) (or <n> for an unknown enumerator, e.g. a bitwise combo);
    write_cvar accepts Value::Enum(name) (name->value) or a raw U32/I32.
    Verified: HW_ADC_channelConfig[0].triggerMode reads as HW_ADC_TRIGGER_SOFTWARE,
    .xferMode as HW_ADC_XFER_POLLED. 10 unit tests still pass.
    [backend.rs, main.rs]
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2026-07-04 SIL: unify main.c — same tasks + init on both targets
    Chunk 2 of the unification refactor: the SIM (native/SIL) build now runs the
    SAME four FreeRTOS tasks and the SAME io/dev/app init as embedded. Divergence
    is confined to the hw-layer seam and a few small gated blocks.
    - main.c: extract prvAppInit() (all io/dev/app + HW_USB/IO_serial init,
    aggregating bools) and prvCreateTasks() (all four real tasks, same
    names/priorities/stacks). Both entry paths (embedded main, sil_fw_start)
    call prvHwInit + prvAppInit + prvCreateTasks + vTaskStartScheduler.
    - Delete the sim_task_1ms stub and sim_task1msRuns — the real task_1ms
    replaces it. Module includes + extern configs moved out of the #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
    [backend.rs, main.c]
2026-07-04 SIL: sanity suite proves the real firmware runs natively
    - main.c: add four monotonic per-task heartbeat counters (task1msRuns,
    task10msRuns, taskUsbRuns, telemRuns), bumped once per loop-body
    iteration. Target-uniform, volatile; read by DWARF from the SIL driver
    and future State Table signals.
    - pcs_bldc_sil: rewrite the demo into a PASS/FAIL sanity suite that exits
    nonzero on any failure. Checks: boot; all four real tasks advance by
    their expected per-period counts; State Table historian/enum/ZOH; and a
    flagship end-to-end path (encoder -> HW_SPI(sim) -> telemetry -> USB(sim)
    capture) driven purely by DWARF white-box writes, asserting the injected
    270.00 deg / raw 12288 com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
    [main.c, main.rs]
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2026-07-05 Gate driver: spec + dev_gateDriver over the in-package I2C3 bus
    Phase A of the STSPIN32G4 gate-driver bring-up: exercises the whole
    HW_I2C/IO_i2c stack on real hardware (I2C3 is bonded in-package to PC8/PC9,
    no BOOT0/C28 entanglement), while the CYPD3177 bus is blocked on rework.
    - specs: sys~mc_002/003 anchors + fw~mc_001..005 (init validation, lazy
    unlock->program->verify->relock->clear config sequence, STATUS fetch,
    cached accessors, deliberate clear-faults API), all traced to impl+test.
    - HW_I2C_BUS_2 (I2C3, 100 kHz) + I2C3 EV/ER IRQ handlers + IO device at
    0x47 with 8-bit offsets. CubeMX MSP already carried the pin mux.
    - dev_gateDriver mirrors the dev_CYPD3177 shape; first regis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
    [HW_I2C_channels.c, main.c]
2026-07-05 Telemetry: report task200ms profile in the slow tier
    The per-2ms take/reset read 0 in 99 of 100 windows (the task runs once per
    100 windows), burying the real value. Taking it once per slow window makes
    every emitted sample a true per-200ms max.
    [main.c]
2026-07-06 I2C: gate-driver bus to 1 MHz FM+, CYPD bus to 400 kHz
    - I2C3 (in-package, internal pull-ups) at 1 MHz, bench-verified.
    - I2C1 (external, 5.1k pull-ups) at 400 kHz - unverified until the C28
    rework frees the bus; drop back to 100 kHz if rise time is marginal.
    - sclBitRateHz now tracks the real rates so the transfer-timeout formula
    scales with them.
    [HW_I2C_channels.c]
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2026-07-06 PWM drive path: HW_TIM master output enable + IO_PWM; 20 kHz / 253 ns
    - fw~hal_tim_008 (MOE set/clear/report, break latch) + amended 007;
    sys~mc_004 bridge-actuation anchor; fw~io_pwm_001..003
    - IO_PWM: per-phase duty 0..1 + bridge enable over TIM1 MOE, target-
    uniform, mock-tested; MOE commanded off at boot and re-applied after
    HAL PWM_Start force-sets it
    - TIM1 config: 20 kHz center-aligned (ARR 4249), 253 ns dead time
    (DTG 43) via CubeMX round-trip
    - Converter round-trip fixes: I2C IRQ handlers mirrored into the
    stm32cube it.c USER CODE block (regen had silently dropped them);
    FreeRTOS wipe list made explicit so host_test_hooks.c survives
    [main.c, pcs_bldc_g4.ioc]
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2026-07-10 sil: add the sim clock / step loop engine
    voyant::engine::Engine ties the parts together: owns the State Table,
    Route Table, and models; borrows a Backend; and step()s the canonical
    per-tick order — advance sim time (monotonic, wall-clock-free) → advance
    models in registration order + record their vsigs → propagate routes →
    advance_tick → sample registered firmware cvars into the historian. A
    model output routed to a cvar lands in firmware before advance_tick of
    the same step.
    - sample_cvar / add_model / add_route(+suspend/resume) registration.
    - Perf: each model's vsig ids and the sampled-cvar list are resolved once,
    so the hot loop never calls Model::signals() (no per-tick all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
    [lib.rs, main.rs]
2026-07-10 voyant: settled per-route latency + step-time wiring validation
    Replaces the interim one-hop-per-tick route semantics with the settled
    "B with annotations" design: forward dataflow has zero added latency; the
    one unavoidable tick of feedback separation is an explicit, physical ZOH cut.
    - Routes gain per-route latency (0 = same-tick forward, 1 = delayed ZOH cut;
    u32, >1 rejected). add()/add_with_latency(); Engine::add_delayed_route().
    - Engine step: validate-if-dirty -> propagate delayed routes from a pre-tick
    snapshot -> per member, resolve the zero-latency DAG in topological order
    with fresh reads (a->b->c resolves same tick), then advance.
    - RouteTable::validate(member_names): singl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
    [backend.rs, lib.rs, main.rs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]
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2026-07-10 voyant: fix forward-flow validation bug + demote Backend to internal seam
    Fix 1 (the bug): RouteTable::check_forward_flow folded availability in
    route-INSERTION order while the spec requires topological order. A chain of
    >=2 unowned intermediates authored anti-topologically under-propagated, letting
    a transitively-backward zero-latency route pass validation (a silent one-tick
    delay at runtime). Now folds in the zero-latency topological route order that
    validate() already computes; dropped the dead pre-sort. Adds a regression test
    that fails against the old insertion-order fold.
    Fix 2: FirmwareMember driven-cvar flush now logs a Warning on an unregistered
    id (Err), symmetric with the sample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
    [backend.rs, lib.rs, main.rs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]
2026-07-10 voyant: auto whole-namespace cvar mirroring (delete drive/sample)
    Collapse the explicit drive_cvar/sample_cvar declarations into automatic
    whole-namespace cvar mirroring — the documented D12 end-state.
    - dwarf.rs: enumerate every traceable leaf (recurse structs, expand arrays,
    capture array dims). Exclusion policy: default array-size threshold 32
    (drops stacks/ucHeap/512-byte buffers), multi-dim/unknown-length + non-data
    leaves skipped, depth/leaf safety cap.
    - backend.rs: FirmwareMember enumerates + registers the namespace once at
    enable, caching a resolved addr/type handle per leaf (sweep never re-resolves
    DWARF). Out-sync sweeps all leaves memory->table (record_mirror); in-sy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
    [backend.rs, main.rs, route.rs]
2026-07-10 SIL performance: release builds, phase-isolated measurement, O(bytes) sweep
    - run_sil.sh defaults to release Rust + optimized firmware DLL (--debug keeps
    the -O0 dev flavor; PCS_OPT_LEVEL toolchain knob; separate build dirs)
    - suite perf report isolates firmware / engine / sweep+flush phases
    - shadow-snapshot memcmp sweep: unchanged ranges cost one compare; only
    changed chunks decode + record
    - dense-index State Table hot path: no string hashing per tick; route
    endpoints memoize indices, guarded against cross-table misuse (fail loud)
    - 496 us -> ~9 us per step (2x -> ~110x realtime); firmware itself ~4 us
    [backend.rs, main.rs, route.rs]
2026-07-10 SIL storage + build headroom: columnar historian, one-type rule, -O3/LTO
    - typed per-signal columns (times + native values; Boxed only for Enum/Bytes
    signals): 40 -> 12-16 B/sample, no Value boxing on the hot record path
    - one signal = one Value type for life: a mismatched record is a hard
    TableError::TypeMismatch (fail loud); migration machinery deleted
    - API ripple: current_value/value_at return Value by value; changes()
    materializes
    - firmware release flavor: -O3 -flto -ffat-lto-objects -g (PCS_LTO knob);
    429-leaf DWARF canary unchanged; no -O3-exposed firmware findings
    - full step ~9 -> ~7.6 us (~130x realtime)
    [backend.rs, main.rs, member.rs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]
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2026-07-10 voyant: tighten comments throughout
    Comments/docs only, zero code changes (85 tests + full suite green).
    Module docs to ~10 lines, item docs to 1-3, owner rulings kept as tight
    bullets, SAFETY comments kept. Net -311 lines.
    [backend.rs, lib.rs, main.rs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]
2026-07-10 voyant: function-DIE anchor fallback for ELF/LTO loads
    The ASLR anchor derivation intersected exports with DWARF *variables* only.
    On the Linux .so (-O3 -flto), the exported data statics never reach .dynsym,
    so the intersection was empty and load aborted. Fall back to exported symbols
    matching DWARF *functions* (DW_AT_low_pc) — the sil_fw_* control ABI is always
    exported and in DWARF. Windows keeps the variable strategy (verified).
    - dwarf: subprogram low_pc map (handles DWARF5 addrx), func_addr/counts
    - backend: variables -> functions -> explicit-override order; override now
    accepts a function name; failure error reports export/var/func counts
    [backend.rs]
2026-07-10 voyant: strip Mach-O leading underscore in anchor matching
    macOS builds without LTO yet hit the same no-anchor failure: Mach-O export
    tables decorate C symbols (_sil_fw_start) while DWARF holds source names, so
    no export could ever string-match. Try each export name direct, then with one
    leading underscore stripped (unconditional — unambiguous, never fires on
    PE/ELF). A stripped match returns the DWARF name, which is also what dlsym
    wants at runtime (it re-adds the underscore).
    [backend.rs]
2026-07-10 SIL: white-box per-tick diag table + coro frame-geometry binding
    macOS aarch64 multi-tick cadence hunt.
    - pcs_bldc_sil: PCS_SIL_DIAG=1 prints a post-boot per-tick table
    (xTickCount, xNextTaskUnblockTime, the 4 heartbeat counters) read by
    DWARF straight from firmware memory. Print-only; wired into CI as a
    temporary job-level env so the macOS runner acts as a remote debugger.
    - coro: hoist frame size + entry/arg/return offsets into a shared
    coro_frame.h included by both coro.c and coro_switch_aarch64.S (asm
    now derives #CORO_FRAME_BYTES), plus _Static_asserts on the layout
    invariants. Verified aarch64 cpp output is byte-identical (#160).
    Static hunt: aarch64 .S re-derived against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
    [main.rs]
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2026-07-10 SIL diag: dump resolved static addresses
    The task_10ms probes showed the 10ms task blocks correctly for 10 ticks
    on macOS while task10msRuns/telemRuns still read +1/tick and match
    task1msRuns's sequence exactly -> the anomaly is a voyant DWARF
    read-address fault for file-scope statics on Mach-O, not scheduling.
    Add Firmware::resolve_addr and print each counter's resolved runtime
    address in the diag so CI's macOS runner shows whether distinct statics
    collapse to one address (confirming the aliasing).
    [backend.rs, main.rs]
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
